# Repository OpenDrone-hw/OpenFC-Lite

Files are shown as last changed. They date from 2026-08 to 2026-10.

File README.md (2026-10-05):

# OpenFC-Lite

Open source Betaflight flight controller built on the RP2354B, 30.5 x 30.5 mm
mounting pattern, part of the incutec OpenDrone line.

<p>
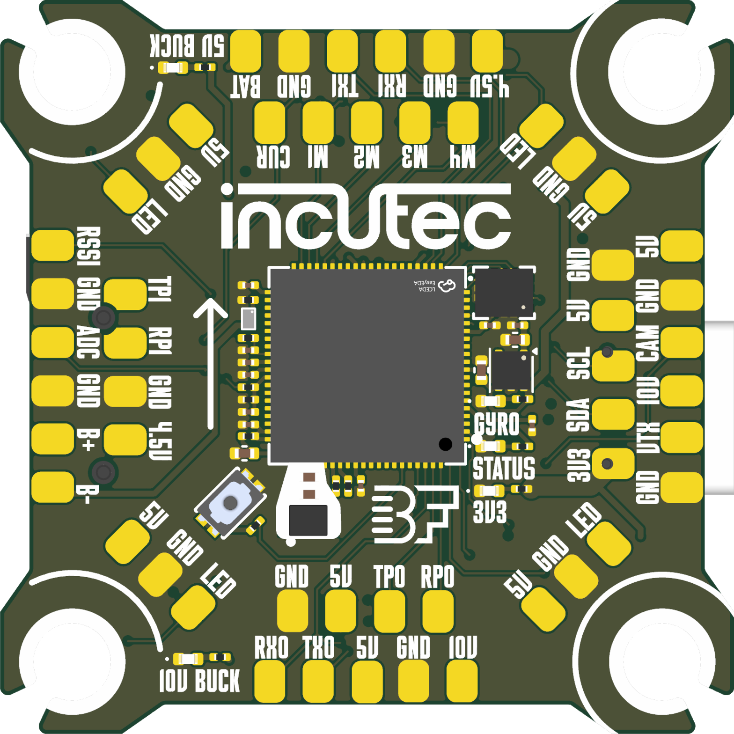
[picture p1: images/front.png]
OpenFC-Lite top

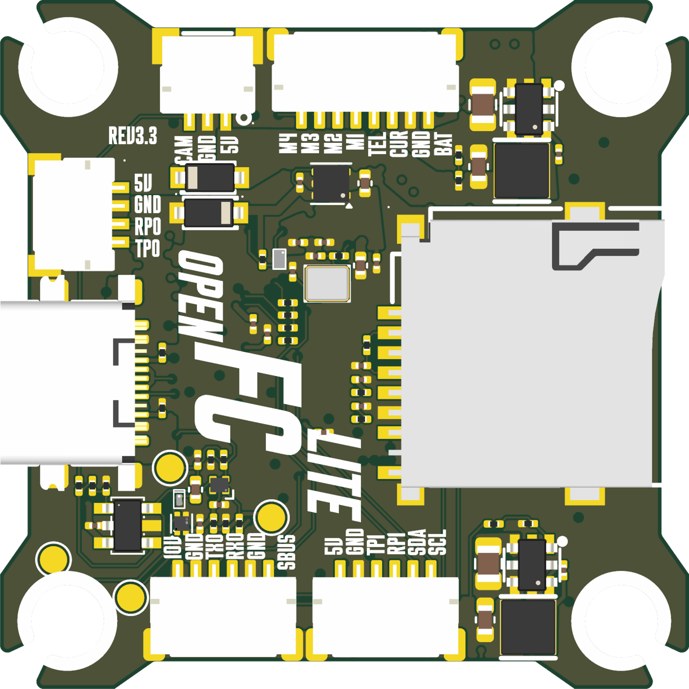
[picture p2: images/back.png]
OpenFC-Lite bottom

</p>







## Specifications

| | |
|---|---|
| Firmware | Betaflight |
| MCU | RP2354B |
| IMU | BMI270 |
| Barometer | None |
| Blackbox | microSD |
| OSD | Analog and digital |
| UARTs | 4 |
| Motor outputs | 4x DShot, bidirectional |
| RX | External, CRSF or SBUS |
| Input | 3-8S* LiPo (9.0-33.6 V) |
| BEC | 10 V switchable + 5 V always-on, 3.5 A |
| Current sense | Yes |
| USB | USB-C |
| Mounting | 30.5 x 30.5 mm, 4.0 mm holes |
| Dimensions | 37.9 x 37.9 mm |
| PCB | 6-layer, 1.6 mm |

* Also runs on 2S; the 10 V VTX output then follows the battery voltage instead of holding 10 V.

Technical write-up, part list and layout constraints: [AGENTS.md](AGENTS.md).

## In the line

What pairs with what, and what is available:
[opendrone.be](https://opendrone.be).

## Contributing

See [CONTRIBUTING.md](CONTRIBUTING.md).

## License

Hardware licensed under [CERN-OHL-S-2.0](https://ohwr.org/cern_ohl_s_v2.txt),
see [LICENSE](LICENSE).

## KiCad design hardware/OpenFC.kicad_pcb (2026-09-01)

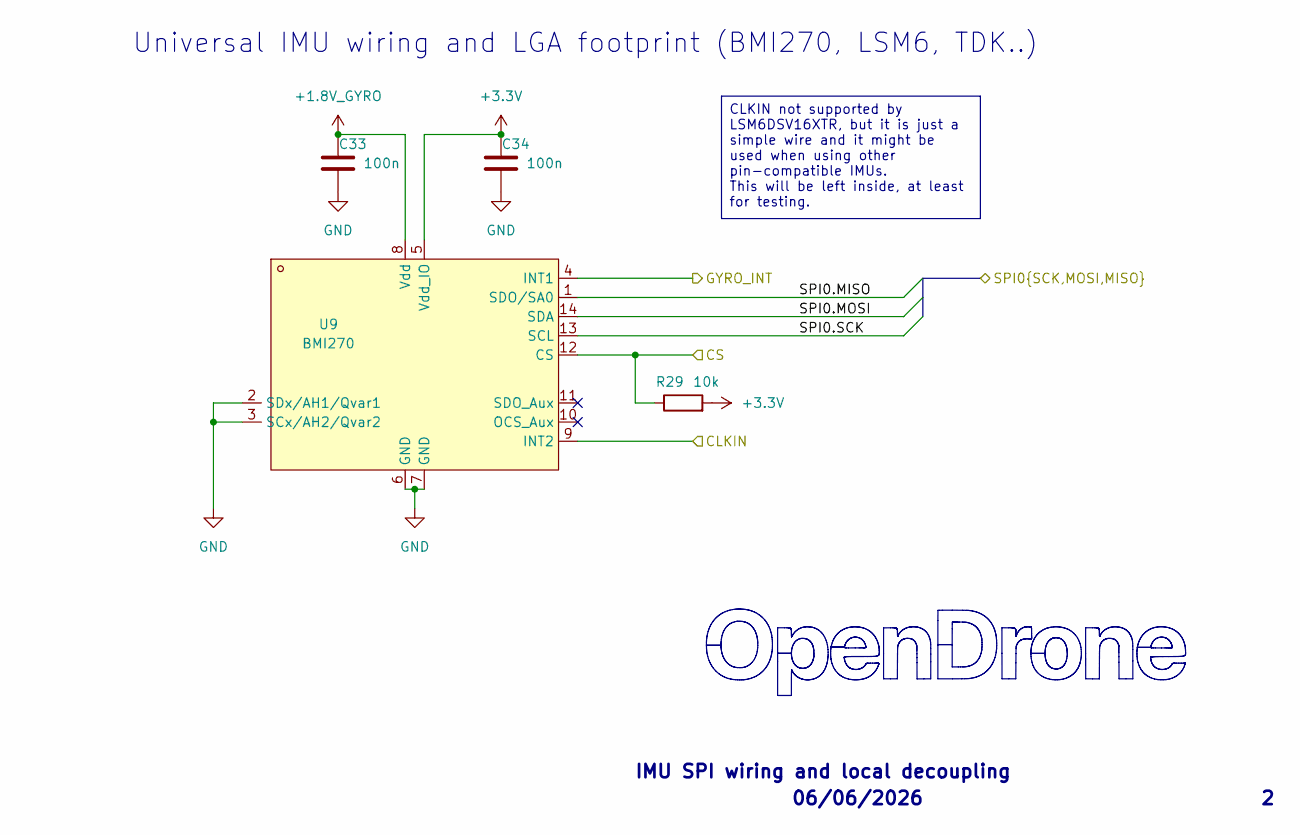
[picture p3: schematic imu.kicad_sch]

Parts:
C33, C34: 100n; C_0201_0603Metric; MPN GRM033R61E104KE14D; LCSC C76939
R29: 10k; R_0201_0603Metric; MPN RC0201FR-0710KL; LCSC C106225
U9: BMI270; LGA-14_L3.0-W2.5-P0.50-BR; MPN BMI270; LCSC C2836813

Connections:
+1.8V_GYRO: C33.1, U9.8 (Vdd); also elsewhere on the board
+3.3V: C34.1, R29.2, U9.5 (Vdd_IO); also elsewhere on the board
/IMU/CLKIN: U9.9 (INT2); also elsewhere on the board
/IMU/CS: R29.1, U9.12 (CS); also elsewhere on the board
/IMU/GYRO_INT: U9.4 (INT1); also elsewhere on the board
/IMU/SPI0.MISO: U9.1 (SDO/SA0); also elsewhere on the board
/IMU/SPI0.MOSI: U9.14 (SDA); also elsewhere on the board
/IMU/SPI0.SCK: U9.13 (SCL); also elsewhere on the board
GND: C33.2, C34.2, U9.2 (SDx/AH1/Qvar1), U9.3 (SCx/AH2/Qvar2), U9.6 (GND), U9.7 (GND); also elsewhere on the board

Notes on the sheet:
06/06/2026
IMU SPI wiring and local decoupling
Universal IMU wiring and LGA footprint (BMI270, LSM6, TDK..)
CLKIN not supported by LSM6DSV16XTR, but it is just a simple wire and it might be used when using other pin-compatible IMUs. This will be left inside, at least for testing.

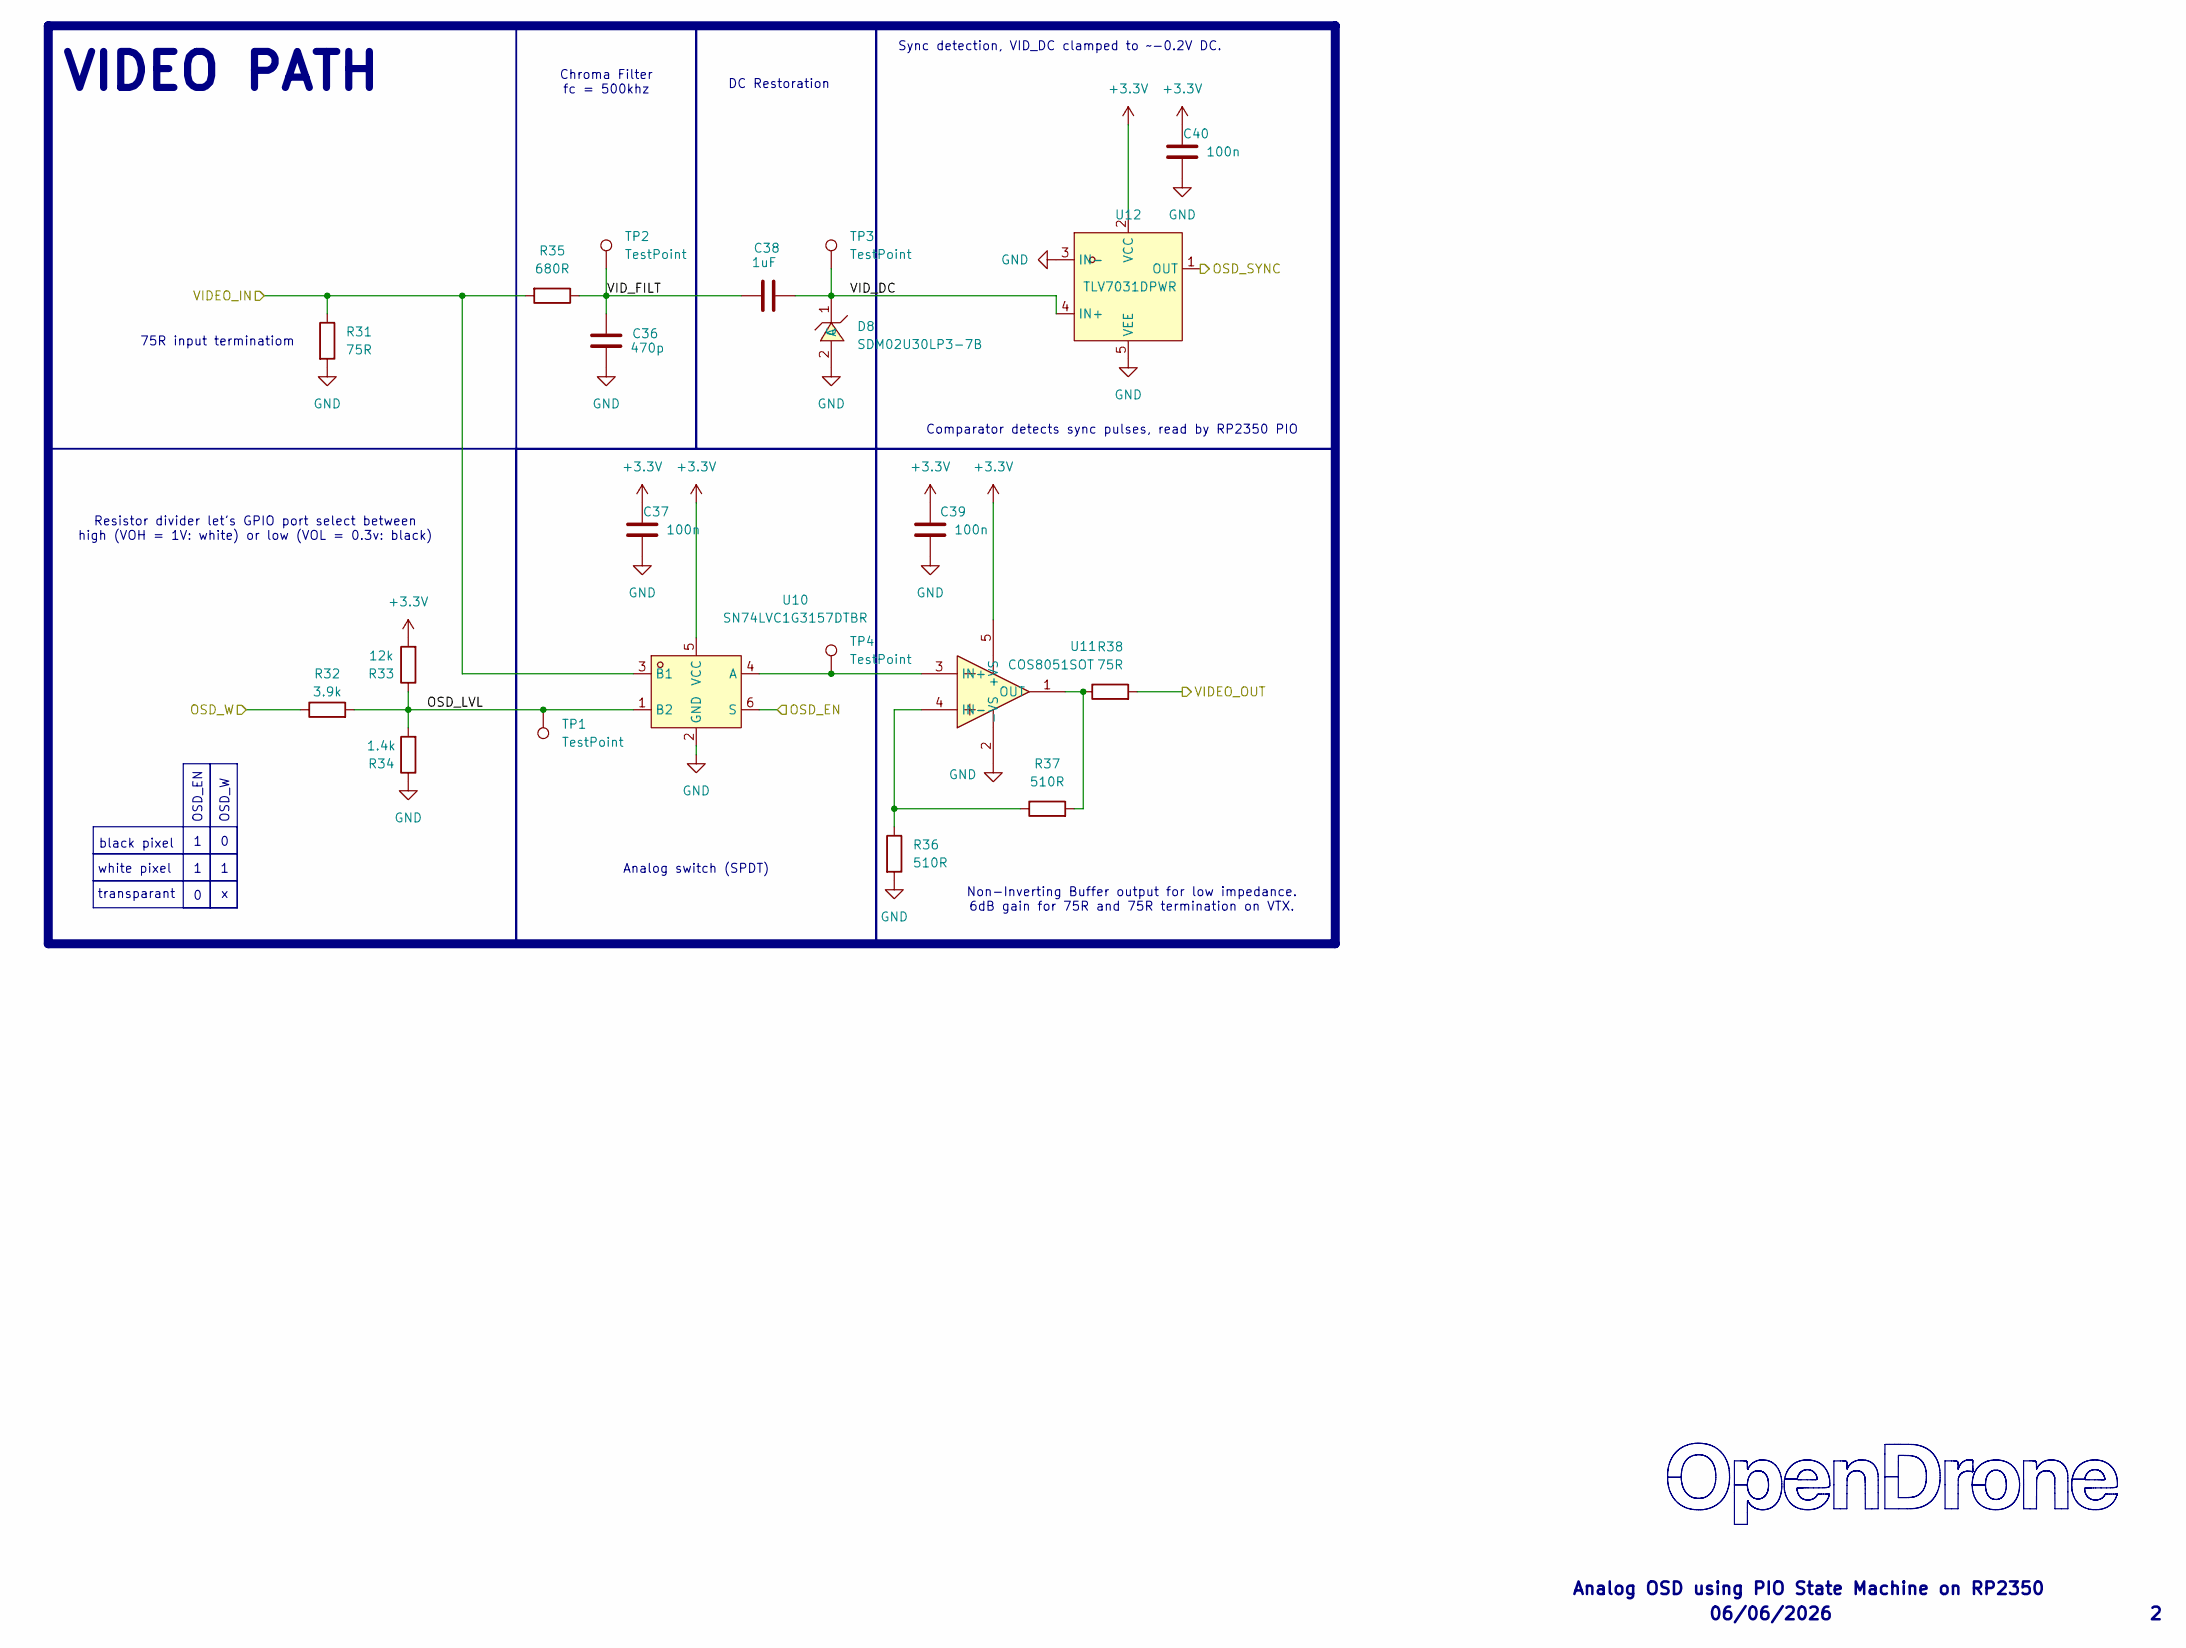
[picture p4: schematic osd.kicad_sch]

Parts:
C36: 470p; C_0201_0603Metric; MPN CC0201JRX7R9BB471; LCSC C526944
C37, C39, C40: 100n; C_0201_0603Metric; MPN GRM033R60J104KE19D; LCSC C76928
C38: 1uF; C_0402_1005Metric; MPN CL05A105KA5NQNC; LCSC C52923
D8: SDM02U30LP3-7B; X3-DFN0603-2_L0.6-W0.3-RD; MPN SDM02U30LP3-7B; LCSC C151629
R31, R38: 75R; R_0201_0603Metric; MPN RC0201FR-0775RL; LCSC C274878
R32: 3.9k; R_0201_0603Metric; MPN RC0201FR-073K9L; LCSC C273280
R33: 12k; R_0201_0603Metric; MPN 0201WMF1202TEE; LCSC C270363
R34: 1.4k; R_0201_0603Metric; MPN 0201WMF1401TEE; LCSC C423739
R35: 680R; R_0201_0603Metric; MPN 0201WMF6800TEE; LCSC C473509
R36, R37: 510R; R_0201_0603Metric; MPN RC0201FR-07510RL; LCSC C57784
TP1, TP2, TP3, TP4: TestPoint; TestPoint_Pad_D1.5mm
U10: SN74LVC1G3157DTBR; X2SON-6_L1.0-W0.8-BL; MPN SN74LVC1G3157DTBR; LCSC C2673087
U11: COS8051SOT; SOT-23-5_L3.0-W1.7-P0.95-LS2.8-BR; MPN COS8051SOT; LCSC C7463385
U12: TLV7031DPWR; X2SON-4_L0.8-W0.8-P0.48-TL-A; MPN TLV7031DPWR; LCSC C2876045

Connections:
+3.3V: C37.1, C39.1, C40.1, R33.2, U10.5 (VCC), U11.5 (+VS), U12.2 (VCC); also elsewhere on the board
/OSD/OSD_EN: U10.6 (S); also elsewhere on the board
/OSD/OSD_LVL: R32.2, R33.1, R34.2, TP1.1 (1_1), U10.1 (B2)
/OSD/OSD_SYNC: U12.1 (OUT); also elsewhere on the board
/OSD/OSD_W: R32.1; also elsewhere on the board
/OSD/VIDEO_IN: R31.1, R35.2, U10.3 (B1); also elsewhere on the board
/OSD/VIDEO_OUT: R38.2; also elsewhere on the board
/OSD/VID_DC: C38.2, D8.1 (C), TP3.1 (1_1), U12.4 (IN+)
/OSD/VID_FILT: C36.1, C38.1, R35.1, TP2.1 (1_1)
GND: C36.2, C37.2, C39.2, C40.2, D8.2 (A), R31.2, R34.1, R36.2, U10.2 (GND), U11.2 (-VS), U12.3 (IN-), U12.5 (VEE); also elsewhere on the board
unnamed: TP4.1 (1_1), U10.4 (A), U11.3 (IN+)
unnamed: R36.1, R37.1, U11.4 (IN-)
unnamed: R37.2, R38.1, U11.1 (OUT)

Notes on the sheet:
black pixel
Comparator detects sync pulses, read by RP2350 PIO
06/06/2026
Analog OSD using PIO State Machine on RP2350
Sync detection, VID_DC clamped to ~-0.2V DC.
Non-Inverting Buffer output for low impedance. 6dB gain for 75R and 75R termination on VTX.
white pixel
75R input terminatiom
OSD_W
Chroma Filter fc = 500khz
VIDEO PATH
Analog switch (SPDT)
OSD_EN
transparant
DC Restoration
Resistor divider let's GPIO port select between high (VOH = 1V: white) or low (VOL = 0.3v: black)

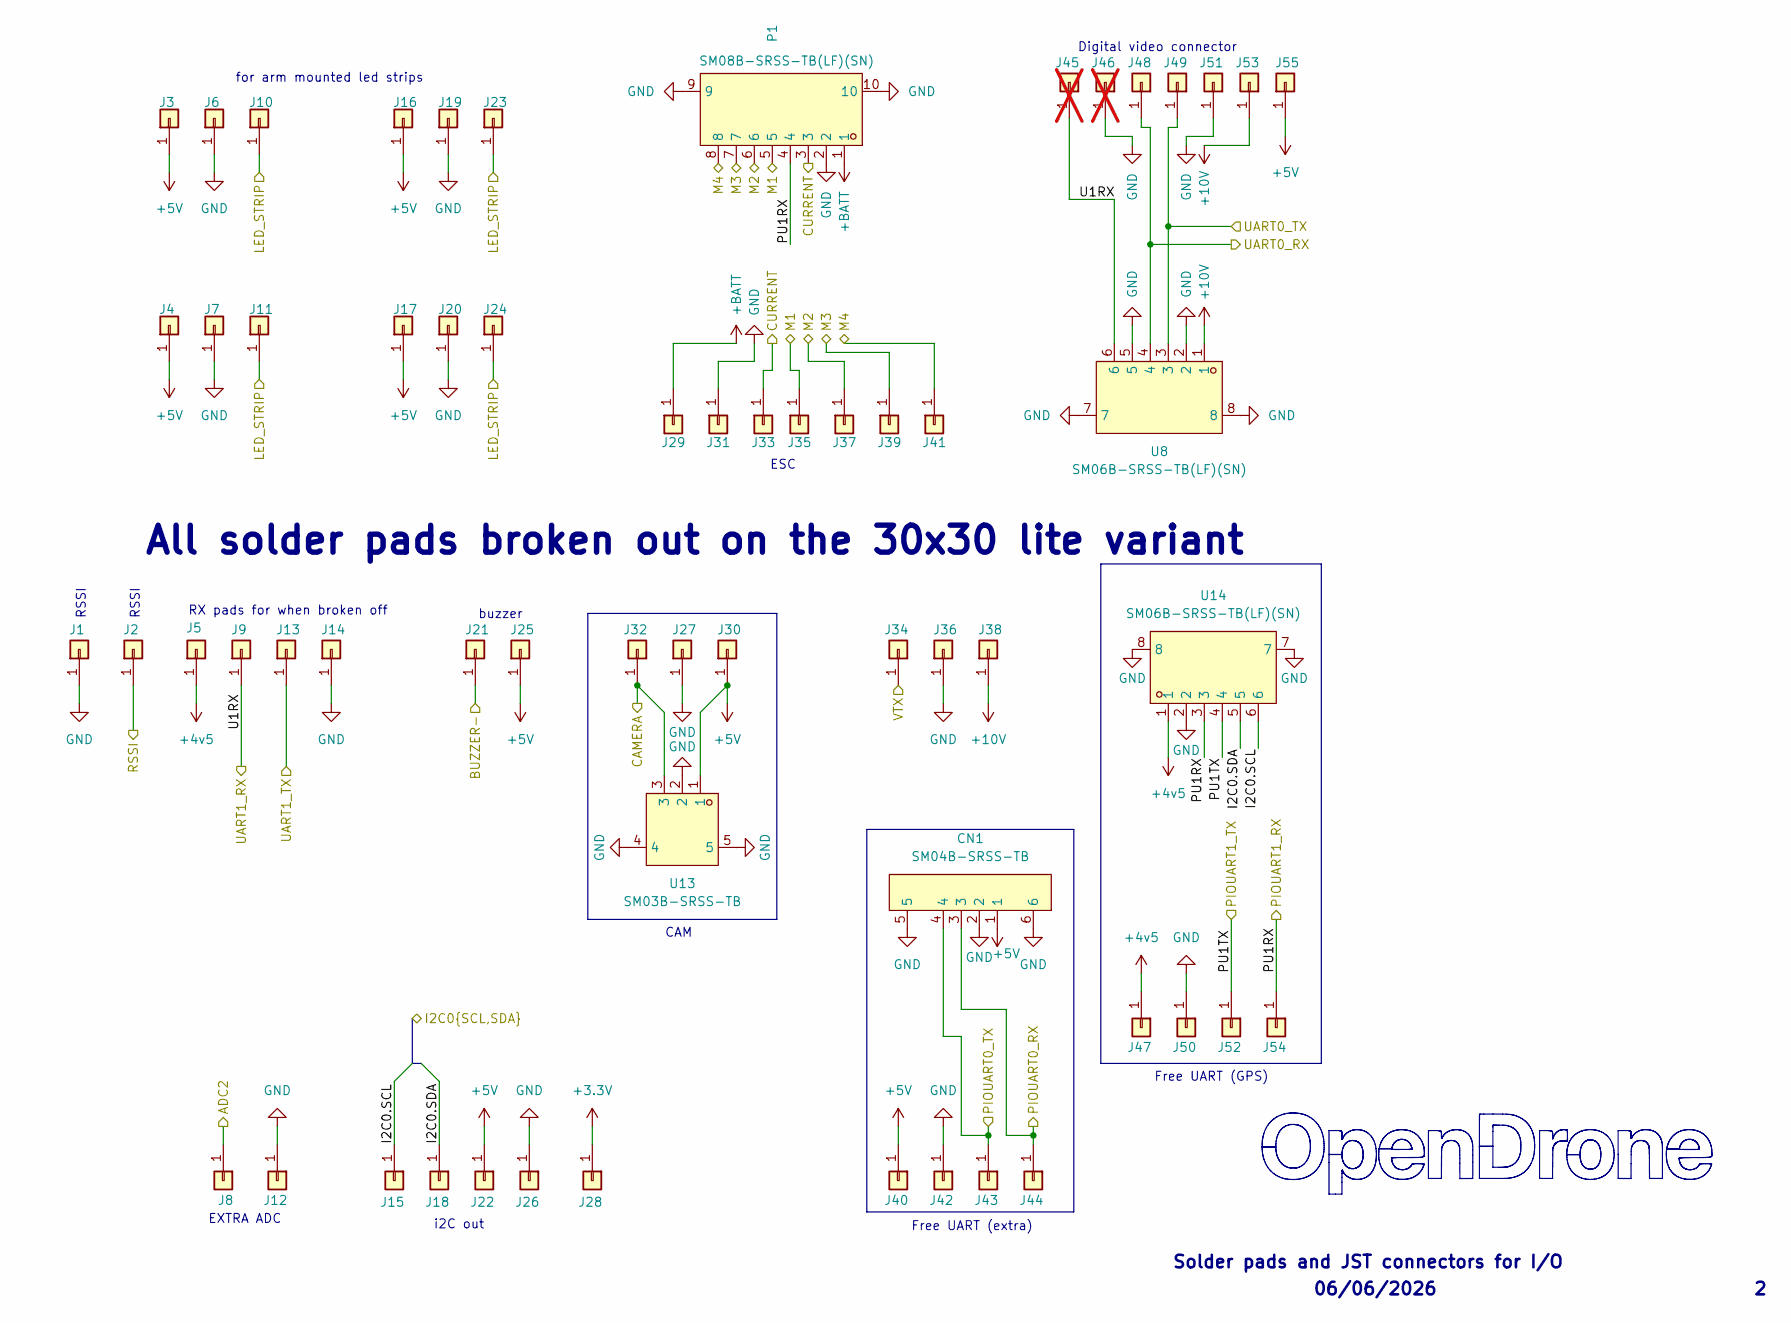
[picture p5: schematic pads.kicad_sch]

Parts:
CN1: SM04B-SRSS-TB; CONN-SMD_4P-P1.00_SM04B-SRSS-TB-LF-SN; MPN SM04B-SRSS-TB(LF)(SN); LCSC C160404
J1, J2, J3, J4, J5, J6, J7, J8, J9, J10, J11, J12, J13, J14, J15, J16, J17, J18, J19, J20, J21, J22, J23, J24, J25, J26, J27, J28, J29, J30, J31, J32, J33, J34, J35, J36, J37, J38, J39, J40, J41, J42, J43, J44, J47, J48, J49, J50, J51, J52, J53, J54, J55: 5V; small_pad
J45, J46: 5V; small_pad; not fitted
P1: SM08B-SRSS-TB(LF)(SN); CONN-TH_SM08B-SRSS-TB-LF-SN; MPN SM08B-SRSS-TB(LF)(SN); LCSC C160407
U8, U14: SM06B-SRSS-TB(LF)(SN); CONN-SMD_SM06B-SRSS-TB-LF-SN; MPN SM06B-SRSS-TB(LF)(SN); LCSC C160405
U13: SM03B-SRSS-TB; CONN-SMD_SM03B-SRSS-TB-LF-SN-P; MPN SM03B-SRSS-TB(LF)(SN); LCSC C160403

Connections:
+3.3V: J28.1 (Pin_1_1); also elsewhere on the board
+4v5: J5.1 (Pin_1_1), J47.1 (Pin_1_1), U14.1; also elsewhere on the board
+5V: CN1.1, J3.1 (Pin_1_1), J4.1 (Pin_1_1), J16.1 (Pin_1_1), J17.1 (Pin_1_1), J22.1 (Pin_1_1), J25.1 (Pin_1_1), J30.1 (Pin_1_1), J40.1 (Pin_1_1), J55.1 (Pin_1_1), U13.1; also elsewhere on the board
+10V: J38.1 (Pin_1_1), J53.1 (Pin_1_1), U8.1; also elsewhere on the board
+BATT: J29.1 (Pin_1_1), P1.1; also elsewhere on the board
/OSD/VIDEO_IN: J32.1 (Pin_1_1), U13.3; also elsewhere on the board
/OSD/VIDEO_OUT: J34.1 (Pin_1_1); also elsewhere on the board
/PADS/ADC2: J8.1 (Pin_1_1); also elsewhere on the board
/PADS/BUZZER-: J21.1 (Pin_1_1); also elsewhere on the board
/PADS/CURRENT: J33.1 (Pin_1_1), P1.3; also elsewhere on the board
/PADS/I2C0.SCL: J15.1 (Pin_1_1), U14.6; also elsewhere on the board
/PADS/I2C0.SDA: J18.1 (Pin_1_1), U14.5; also elsewhere on the board
/PADS/LED_STRIP: J10.1 (Pin_1_1), J11.1 (Pin_1_1), J23.1 (Pin_1_1), J24.1 (Pin_1_1); also elsewhere on the board
/PADS/M1: J35.1 (Pin_1_1), P1.5; also elsewhere on the board
/PADS/M2: J37.1 (Pin_1_1), P1.6; also elsewhere on the board
/PADS/M3: J39.1 (Pin_1_1), P1.7; also elsewhere on the board
/PADS/M4: J41.1 (Pin_1_1), P1.8; also elsewhere on the board
/PADS/PIOUART0_RX: CN1.3, J44.1 (Pin_1_1); also elsewhere on the board
/PADS/PIOUART0_TX: CN1.4, J43.1 (Pin_1_1); also elsewhere on the board
/PADS/PU1RX: J54.1 (Pin_1_1), P1.4, U14.3; also elsewhere on the board
/PADS/PU1TX: J52.1 (Pin_1_1), U14.4; also elsewhere on the board
/PADS/RSSI: J2.1 (Pin_1_1); also elsewhere on the board
/PADS/U1RX: J9.1 (Pin_1_1), J45.1, U8.6; also elsewhere on the board
/PADS/UART0_RX: J48.1 (Pin_1_1), U8.4; also elsewhere on the board
/PADS/UART0_TX: J49.1 (Pin_1_1), U8.3; also elsewhere on the board
/PADS/UART1_TX: J13.1 (Pin_1_1); also elsewhere on the board
GND: CN1.2, CN1.5, CN1.6, J1.1 (Pin_1_1), J6.1 (Pin_1_1), J7.1 (Pin_1_1), J12.1 (Pin_1_1), J14.1 (Pin_1_1), J19.1 (Pin_1_1), J20.1 (Pin_1_1), J26.1 (Pin_1_1), J27.1 (Pin_1_1), J31.1 (Pin_1_1), J36.1 (Pin_1_1), J42.1 (Pin_1_1), J46.1, J50.1 (Pin_1_1), J51.1 (Pin_1_1), P1.2, P1.9, P1.10, U8.2, U8.5, U8.7, U8.8, U13.2, U13.4, U13.5, U14.2, U14.7, U14.8; also elsewhere on the board

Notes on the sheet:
06/06/2026
RSSI
Free UART (extra)
Solder pads and JST connectors for I/O
i2C out
CAM
All solder pads broken out on the 30x30 lite variant
Free UART (GPS)
buzzer
RX pads for when broken off
ESC
Digital video connector
EXTRA ADC
for arm mounted led strips

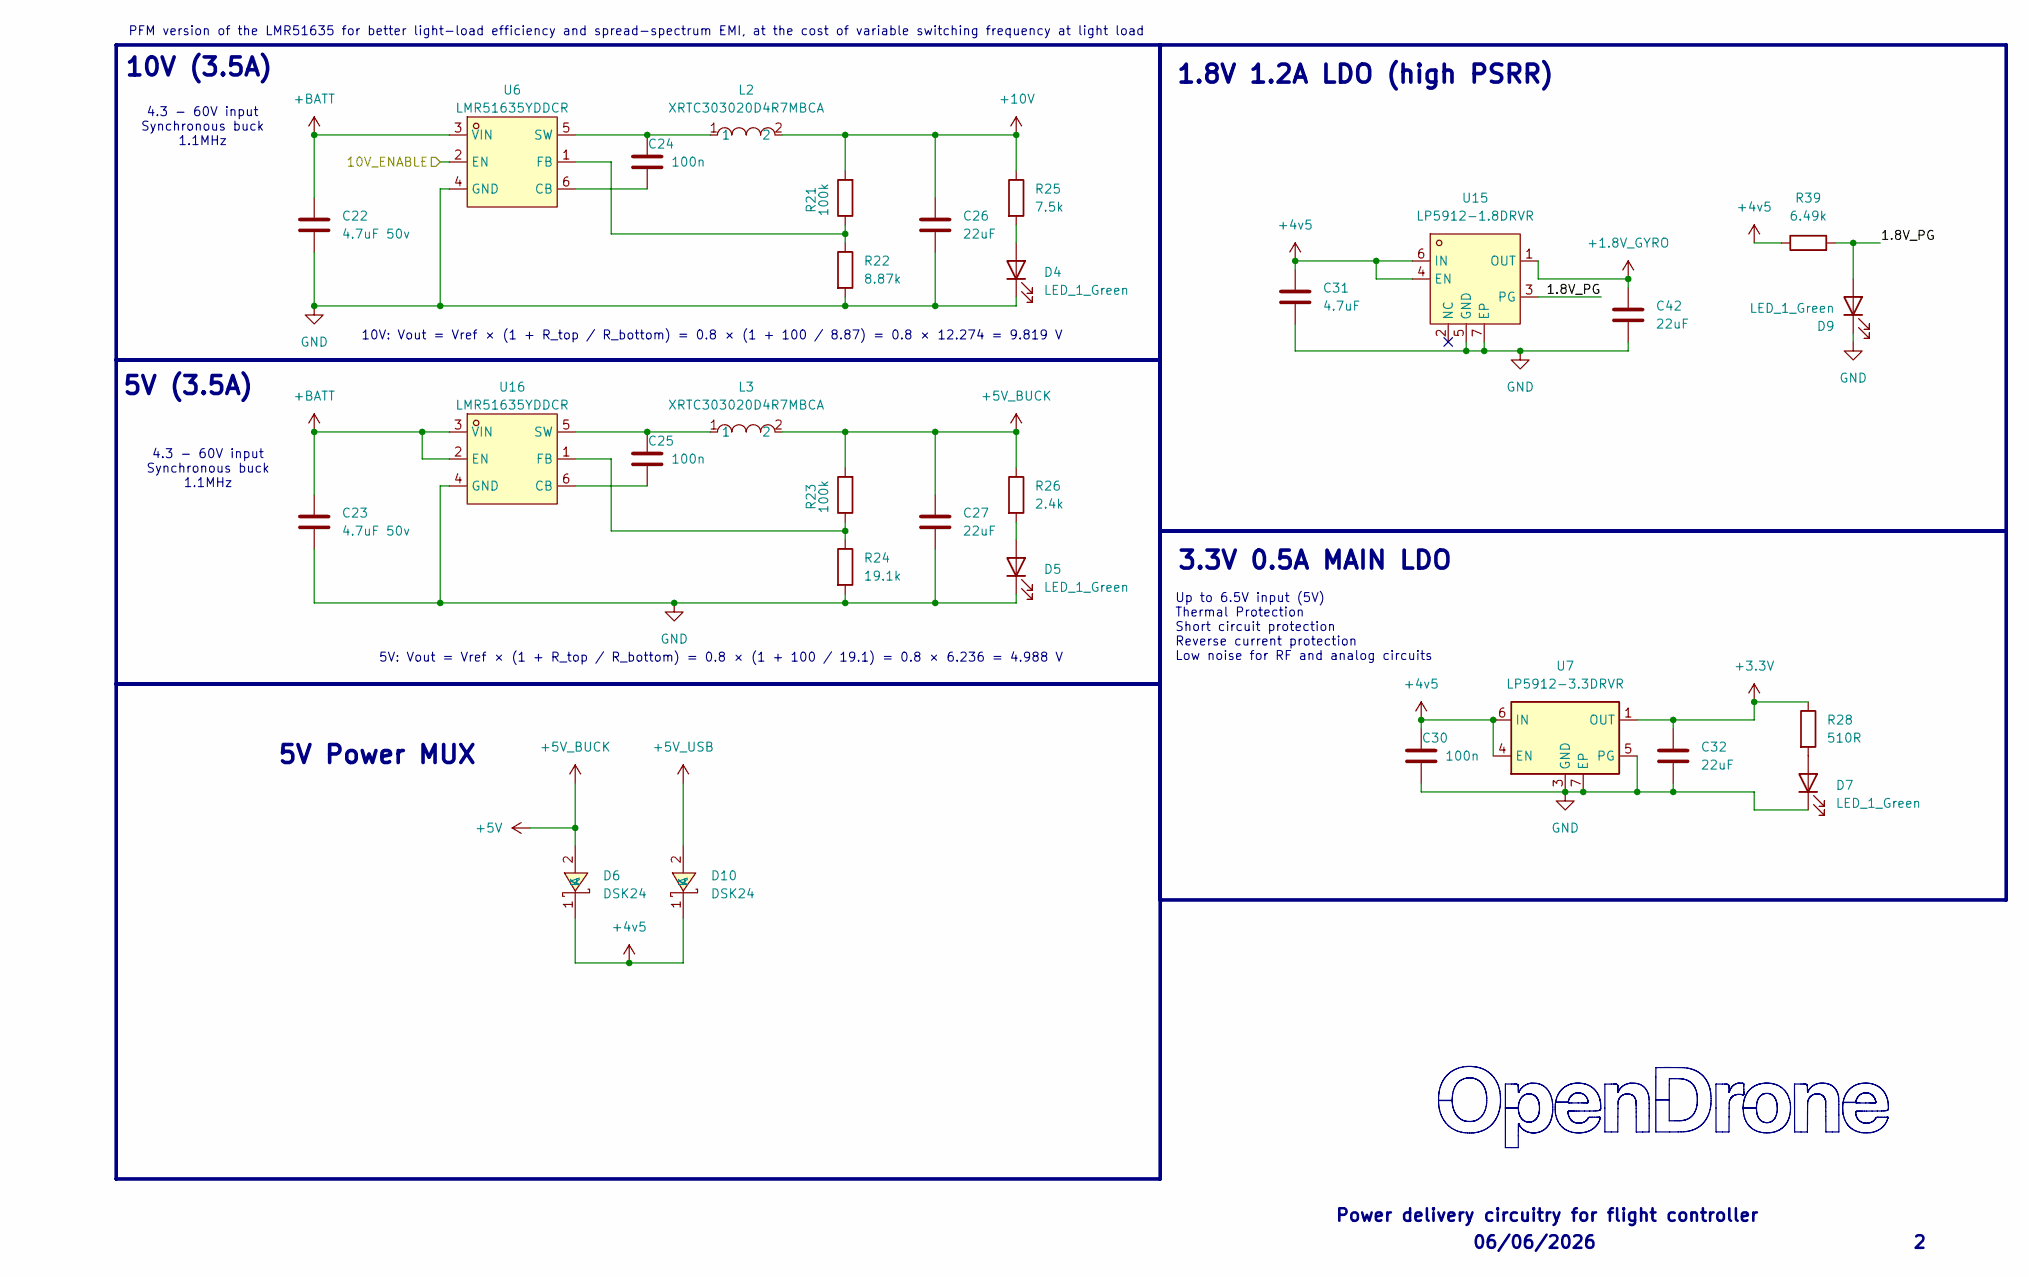
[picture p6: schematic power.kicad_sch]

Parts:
C22, C23: 4.7uF 50v; C_0805_2012Metric; MPN CL21A475KBQNNNE; LCSC C98192
C24, C25, C30: 100n; C_0201_0603Metric; MPN GRM033R61E104KE14D; LCSC C76939
C26, C27: 22uF; C_0603_1608Metric; MPN CL10A226MO7JZNC; LCSC C2762594
C31: 4.7uF; C_0402_1005Metric; MPN CL05A475MP5NRNC; LCSC C23733
C32: 22uF; C_0402_1005Metric; MPN CL05A226MQ5QUNC; LCSC C105226
C42: 22uF; C_0402_1005Metric; MPN GRM155R60J226ME11D; LCSC C415703
D4, D5, D7, D9: LED_1_Green; LED_0402_1005Metric; MPN XL-1005UGC; LCSC C965793
D6, D10: DSK24; SOD-123_L2.8-W1.8-LS3.7-RD; MPN DSK24; LCSC C64890
L2, L3: XRTC303020D4R7MBCA; IND-SMD_L3.0-W3.0_AFE303020S; MPN XRTC303020D4R7MBCA; LCSC C39846837
R21, R23: 100k; R_0201_0603Metric; MPN 0201WMF1003TEE; LCSC C270364
R22: 8.87k; R_0201_0603Metric; MPN RTT018871FTH; LCSC C332577
R24: 19.1k; R_0201_0603Metric; MPN RC-01W1912FT; LCSC C320741
R25: 7.5k; R_0201_0603Metric; MPN RC0201FR-077K5L; LCSC C474437
R26: 2.4k; R_0201_0603Metric; MPN RTT012401FTH; LCSC C166281
R28: 510R; R_0201_0603Metric; MPN RC0201FR-07510RL; LCSC C57784
R39: 6.49k; R_0201_0603Metric; MPN AF0201FR-076K49L; LCSC C2107920
U6, U16: LMR51635YDDCR; SOT-23-6_L2.9-W1.6-P0.95-LS2.8-BL; MPN LMR51635YDDCR; LCSC C45262770
U7: LP5912-3.3DRVR; WSON-6-1EP_2x2mm_P0.65mm_EP1x1.6mm; MPN LP5912-3.3DRVR; LCSC C524780
U15: LP5912-1.8DRVR; WSON-6-1EP_2x2mm_P0.65mm_EP1x1.6mm_ThermalVias; MPN LP5912-1.8DRVR; LCSC C2876234

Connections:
+1.8V_GYRO: C42.1, U15.1 (OUT); also elsewhere on the board
+3.3V: C32.1, R28.1, U7.1 (OUT); also elsewhere on the board
+4v5: C30.1, C31.1, D6.1 (K), D10.1 (K), R39.1, U7.4 (EN), U7.6 (IN), U15.4 (EN), U15.6 (IN); also elsewhere on the board
+5V: C27.1, D6.2 (A), L3.2, R23.2, R26.1; also elsewhere on the board
+5V_USB: D10.2 (A); also elsewhere on the board
+10V: C26.1, L2.2, R21.2, R25.1; also elsewhere on the board
+BATT: C22.1, C23.1, U6.3 (VIN), U16.2 (EN), U16.3 (VIN); also elsewhere on the board
/POWER/1.8V_PG: D9.2 (A), R39.2, U15.3 (PG)
/POWER/10V_ENABLE: U6.2 (EN); also elsewhere on the board
GND: C22.2, C23.2, C26.2, C27.2, C30.2, C31.2, C32.2, C42.2, D4.1 (K), D5.1 (K), D7.1 (K), D9.1 (K), R22.2, R24.2, U6.4 (GND), U7.3 (GND), U7.5 (PG), U7.7 (EP), U15.5 (GND), U15.7 (EP), U16.4 (GND); also elsewhere on the board
unnamed: D4.2 (A), R25.2
unnamed: D5.2 (A), R26.2
unnamed: D7.2 (A), R28.2
unnamed: C24.2, U6.6 (CB)
unnamed: R21.1, R22.1, U6.1 (FB)
unnamed: C24.1, L2.1, U6.5 (SW)
unnamed: C25.2, U16.6 (CB)
unnamed: R23.1, R24.1, U16.1 (FB)
unnamed: C25.1, L3.1, U16.5 (SW)

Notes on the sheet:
5V Power MUX
4.3 - 60V input Synchronous buck 1.1MHz
Power delivery circuitry for flight controller
06/06/2026
10V: Vout = Vref × (1 + R_top / R_bottom) = 0.8 × (1 + 100 / 8.87) = 0.8 × 12.274 = 9.819 V
5V: Vout = Vref × (1 + R_top / R_bottom) = 0.8 × (1 + 100 / 19.1) = 0.8 × 6.236 = 4.988 V
Up to 6.5V input (5V) Thermal Protection Short circuit protection Reverse current protection Low noise for RF and analog circuits
5V (3.5A)
1.8V 1.2A LDO (high PSRR)
PFM version of the LMR51635 for better light-load efficiency and spread-spectrum EMI, at the cost of variable switching frequency at light load
10V (3.5A)
3.3V 0.5A MAIN LDO

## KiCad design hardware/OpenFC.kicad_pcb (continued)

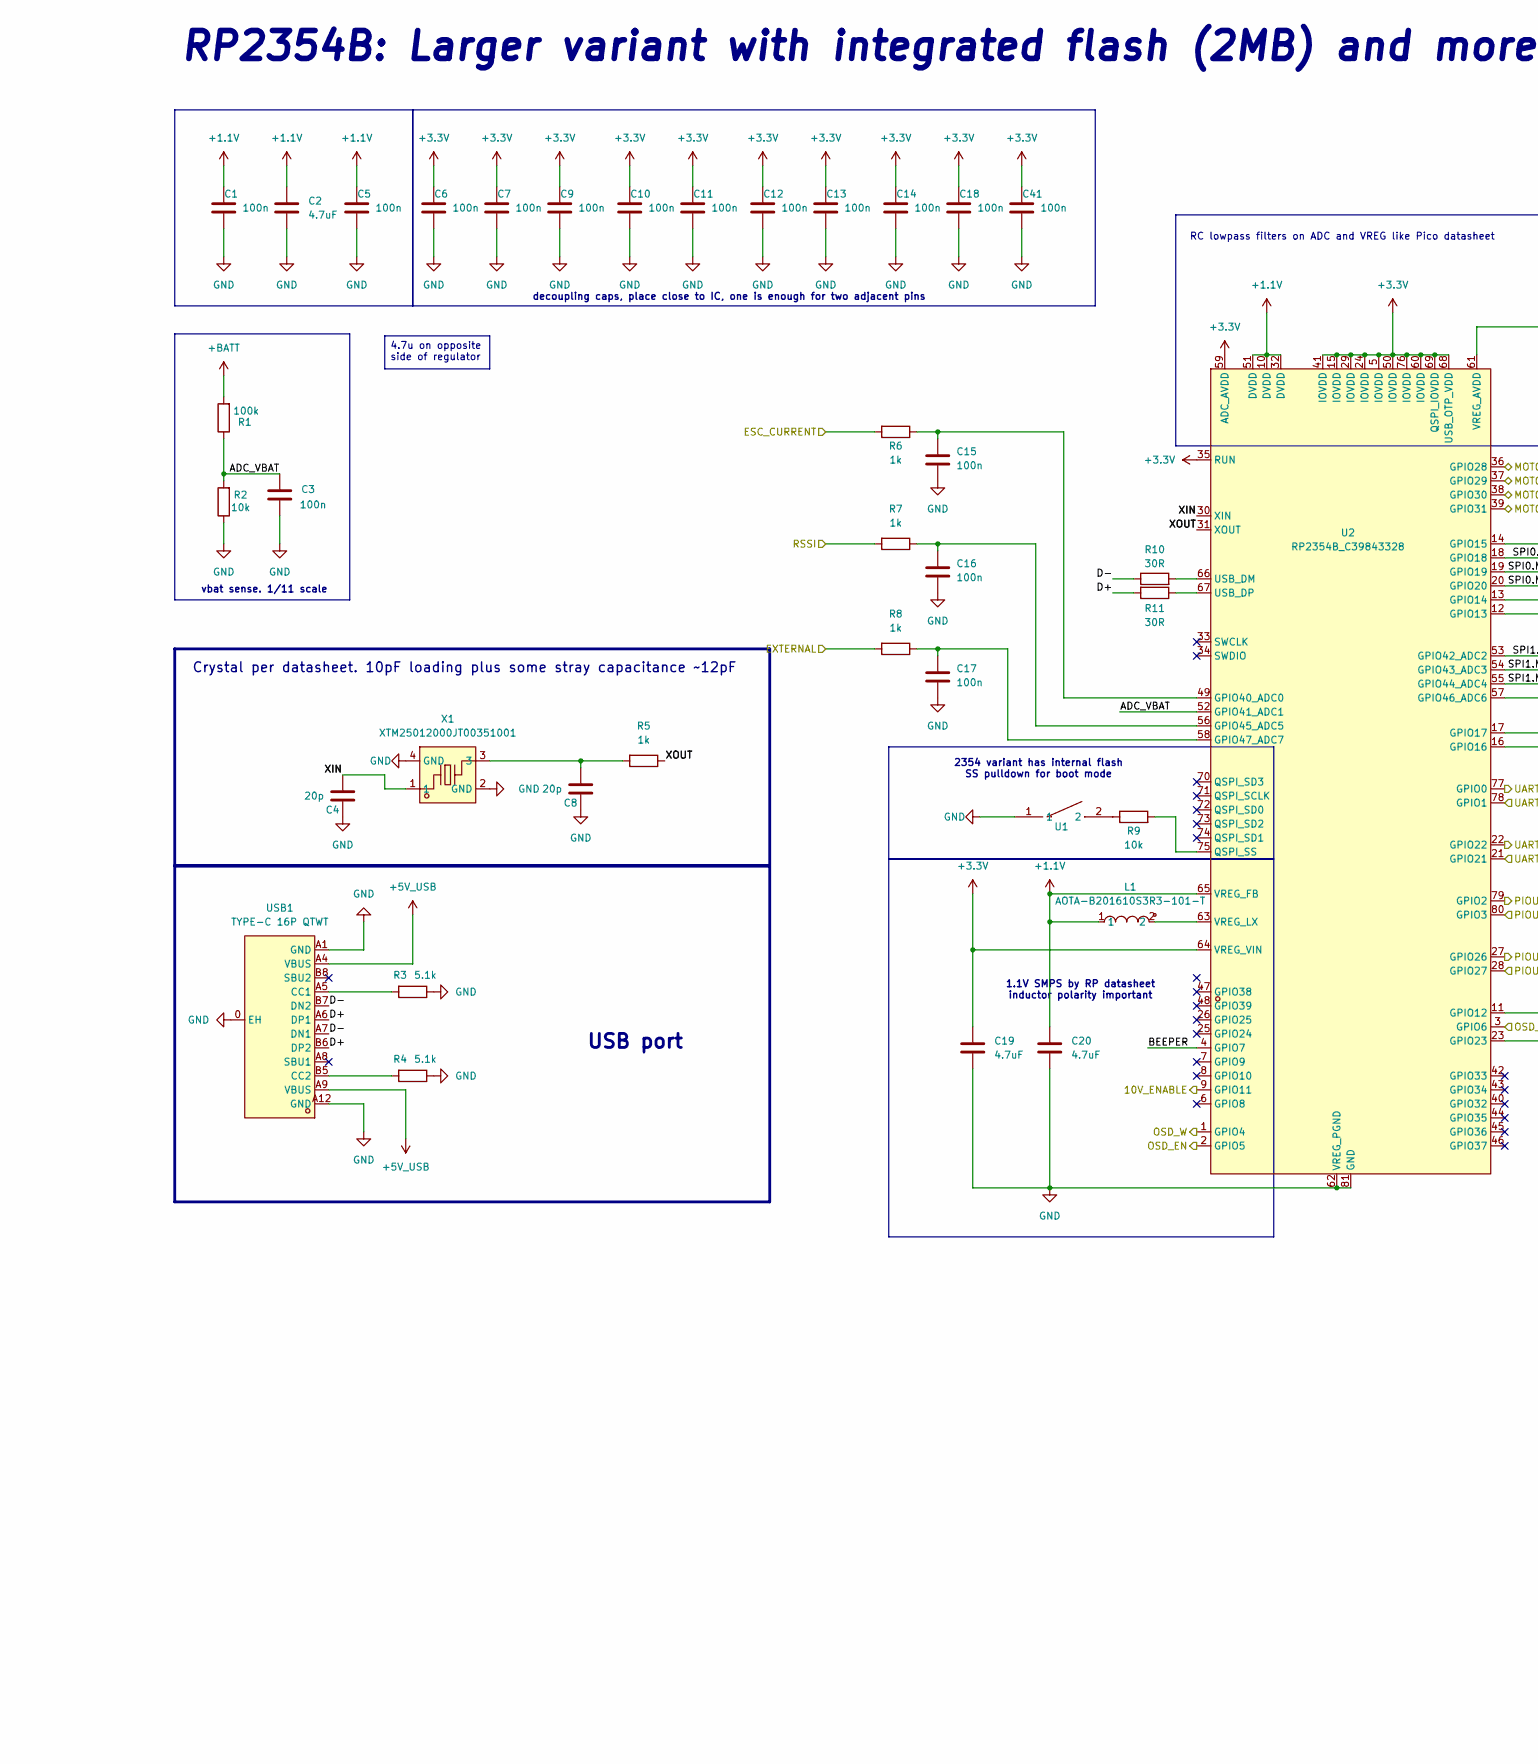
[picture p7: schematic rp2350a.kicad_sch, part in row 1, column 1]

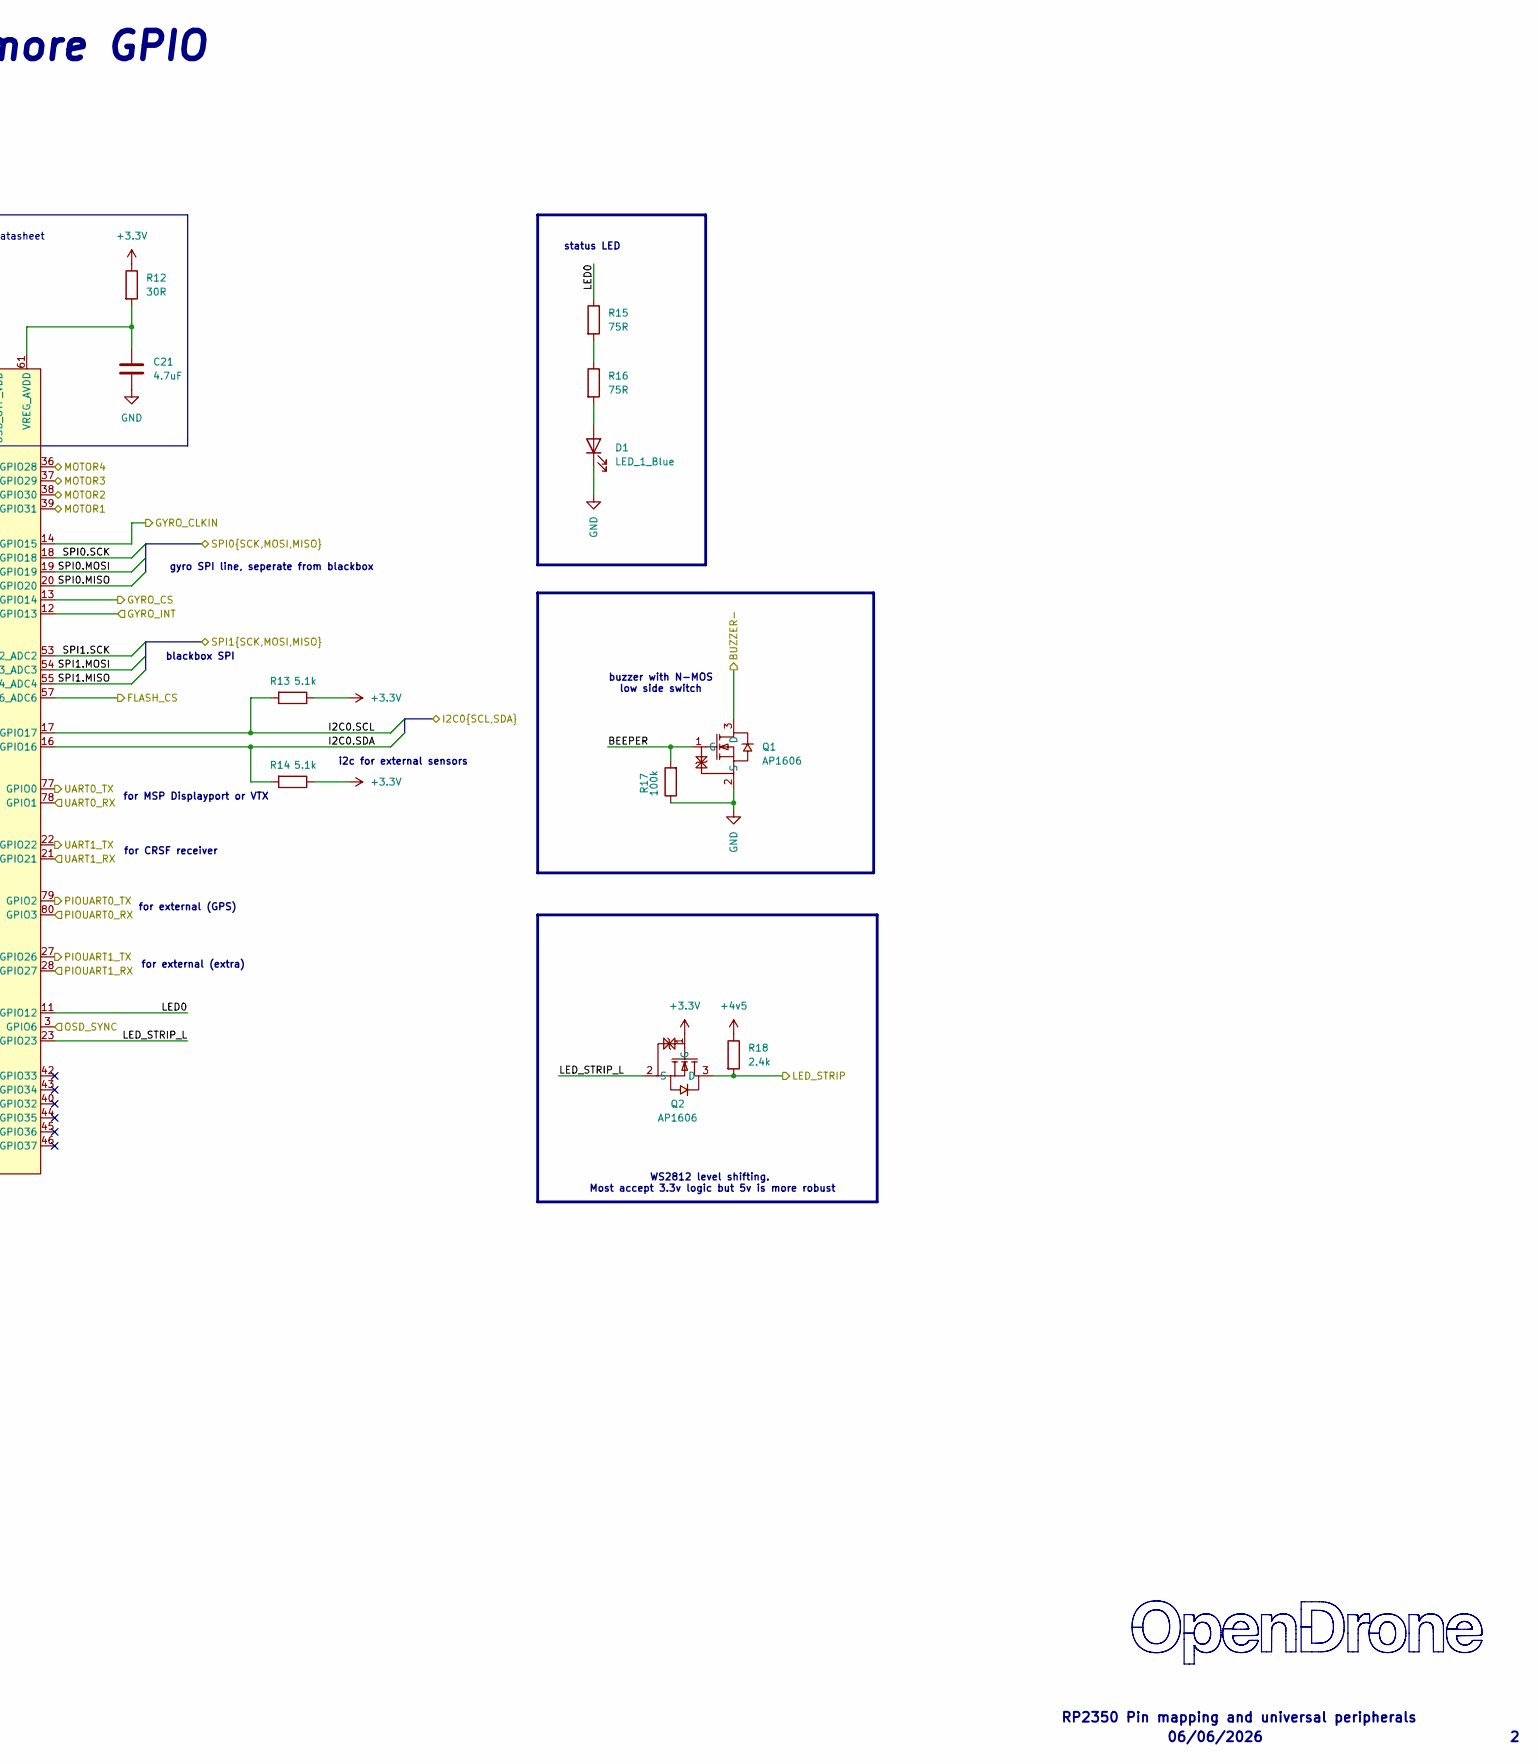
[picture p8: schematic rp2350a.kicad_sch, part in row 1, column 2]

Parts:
C1, C3, C5, C6, C7, C9, C10, C11, C12, C13, C14, C15, C16, C17, C18, C41: 100n; C_0201_0603Metric; MPN GRM033R61E104KE14D; LCSC C76939
C2, C19, C20, C21: 4.7uF; C_0402_1005Metric; MPN CL05A475MP5NRNC; LCSC C23733
C4, C8: 20p; C_0201_0603Metric; MPN GRM0335C1H200JA01D; LCSC C76923
D1: LED_1_Blue; LED_0402_1005Metric; MPN XL-1005UBC; LCSC C22355736
L1: AOTA-B201610S3R3-101-T; IND-SMD_L2.0-W1.6_AOTA-B201610S3R3-101-T; MPN AOTA-B201610S3R3-101-T; LCSC C42411119
Q1, Q2: AP1606; DFN-3L_L1.0-W0.6-P0.65-BR; MPN AP1606; LCSC C2849580
R1, R17: 100k; R_0201_0603Metric; MPN 0201WMF1003TEE; LCSC C270364
R2, R9: 10k; R_0201_0603Metric; MPN RC0201FR-0710KL; LCSC C106225
R3, R4, R13, R14: 5.1k; R_0201_0603Metric; MPN 0201WMF5101TEE; LCSC C270344
R5, R6, R7, R8: 1k; R_0201_0603Metric; MPN 0201WMF1001TEE; LCSC C270365
R10, R11, R12: 30R; R_0201_0603Metric; MPN NQ01WMJ0300TEE; LCSC C778391
R15, R16: 75R; R_0201_0603Metric; MPN RC0201FR-0775RL; LCSC C274878
R18: 2.4k; R_0201_0603Metric; MPN RTT012401FTH; LCSC C166281
U1: TS2306A 240GF MSM 9_C2976675; SW-SMD_4P-L3.0-W2.0-P0.85-LS3.5; MPN TS2306A 240gf MSM 9; LCSC C2976675
U2: RP2354B_C39843328; QFN-80_L10.0-W10.0-P0.40-TL-EP3.4; MPN RP2354B; LCSC C39843328
USB1: TYPE-C 16P QTWT; USB-TYPE-C-SMD_TYPE-C-16P-QTWT; MPN TYPE-C 16P QTWT; LCSC C5187472
X1: XTM25012000JT00351001; CRYSTAL-SMD_4P-L2.5-W2.0-BL-A; MPN XTM25012000JT00351001; LCSC C37635340

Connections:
+1.1V: C1.1, C2.1, C5.1, C20.1, L1.1, U2.10 (DVDD), U2.32 (DVDD), U2.51 (DVDD), U2.65 (VREG_FB)
+3.3V: C6.1, C7.1, C9.1, C10.1, C11.1, C12.1, C13.1, C14.1, C18.1, C19.1, C41.1, Q2.1 (G), R12.1, R13.1, R14.1, U2.5 (IOVDD), U2.15 (IOVDD), U2.24 (IOVDD), U2.29 (IOVDD), U2.35 (RUN), U2.41 (IOVDD), U2.50 (IOVDD), U2.59 (ADC_AVDD), U2.60 (IOVDD), U2.64 (VREG_VIN), U2.68 (USB_OTP_VDD), U2.69 (QSPI_IOVDD), U2.76 (IOVDD); also elsewhere on the board
+4v5: R18.1; also elsewhere on the board
+5V_USB: USB1.A4 (VBUS), USB1.A9 (VBUS); also elsewhere on the board
+BATT: R1.2; also elsewhere on the board
/BLACKBOX/FLASH_CS: U2.57 (GPIO46_ADC6); also elsewhere on the board
/BLACKBOX/SPI1.MISO: U2.55 (GPIO44_ADC4); also elsewhere on the board
/BLACKBOX/SPI1.MOSI: U2.54 (GPIO43_ADC3); also elsewhere on the board
/BLACKBOX/SPI1.SCK: U2.53 (GPIO42_ADC2); also elsewhere on the board
/IMU/CLKIN: U2.14 (GPIO15); also elsewhere on the board
/IMU/CS: U2.13 (GPIO14); also elsewhere on the board
/IMU/GYRO_INT: U2.12 (GPIO13); also elsewhere on the board
/IMU/SPI0.MISO: U2.20 (GPIO20); also elsewhere on the board
/IMU/SPI0.MOSI: U2.19 (GPIO19); also elsewhere on the board
/IMU/SPI0.SCK: U2.18 (GPIO18); also elsewhere on the board
/OSD/OSD_EN: U2.2 (GPIO5); also elsewhere on the board
/OSD/OSD_SYNC: U2.3 (GPIO6); also elsewhere on the board
/OSD/OSD_W: U2.1 (GPIO4); also elsewhere on the board
/PADS/ADC2: R8.2; also elsewhere on the board
/PADS/BUZZER-: Q1.3 (D); also elsewhere on the board
/PADS/CURRENT: R6.2; also elsewhere on the board
/PADS/I2C0.SCL: R13.2, U2.17 (GPIO17); also elsewhere on the board
/PADS/I2C0.SDA: R14.2, U2.16 (GPIO16); also elsewhere on the board
/PADS/LED_STRIP: Q2.3 (D), R18.2; also elsewhere on the board
/PADS/M1: U2.39 (GPIO31); also elsewhere on the board
/PADS/M2: U2.38 (GPIO30); also elsewhere on the board
/PADS/M3: U2.37 (GPIO29); also elsewhere on the board
/PADS/M4: U2.36 (GPIO28); also elsewhere on the board
/PADS/PIOUART0_RX: U2.80 (GPIO3); also elsewhere on the board
/PADS/PIOUART0_TX: U2.79 (GPIO2); also elsewhere on the board
/PADS/PU1RX: U2.28 (GPIO27); also elsewhere on the board
/PADS/PU1TX: U2.27 (GPIO26); also elsewhere on the board
/PADS/RSSI: R7.2; also elsewhere on the board
/PADS/U1RX: U2.21 (GPIO21); also elsewhere on the board
/PADS/UART0_RX: U2.78 (GPIO1); also elsewhere on the board
/PADS/UART0_TX: U2.77 (GPIO0); also elsewhere on the board
/PADS/UART1_TX: U2.22 (GPIO22); also elsewhere on the board
/POWER/10V_ENABLE: U2.9 (GPIO11); also elsewhere on the board
/RP2350A/ADC_VBAT: C3.2, R1.1, R2.2, U2.52 (GPIO41_ADC1)
/RP2350A/BEEPER: Q1.1 (G), R17.2, U2.4 (GPIO7)
/RP2350A/D+: R11.2, USB1.A6 (DP1), USB1.B6 (DP2)
/RP2350A/D-: R10.1, USB1.A7 (DN1), USB1.B7 (DN2)
/RP2350A/LED0: R15.1, U2.11 (GPIO12)
/RP2350A/LED_STRIP_L: Q2.2 (S), U2.23 (GPIO23)
/RP2350A/XIN: C4.2, U2.30 (XIN), X1.1
/RP2350A/XOUT: R5.1, U2.31 (XOUT)
GND: C1.2, C2.2, C3.1, C4.1, C5.2, C6.2, C7.2, C8.1, C9.2, C10.2, C11.2, C12.2, C13.2, C14.2, C15.2, C16.2, C17.2, C18.2, C19.2, C20.2, C21.2, C41.2, D1.1 (K), Q1.2 (S), R2.1, R3.1, R4.1, R17.1, U1.1, U2.62 (VREG_PGND), U2.81 (GND), USB1.0 (EH), USB1.A1 (GND), USB1.A12 (GND), X1.2 (GND), X1.4 (GND); also elsewhere on the board
unnamed: C8.2, R5.2, X1.3
unnamed: D1.2 (A), R16.2
unnamed: R9.1, U1.2
unnamed: R15.2, R16.1
unnamed: C15.1, R6.1, U2.49 (GPIO40_ADC0)
unnamed: C16.1, R7.1, U2.56 (GPIO45_ADC5)
unnamed: C17.1, R8.1, U2.58 (GPIO47_ADC7)
unnamed: R9.2, U2.75 (QSPI_SS)
unnamed: R10.2, U2.66 (USB_DM)
unnamed: R11.1, U2.67 (USB_DP)
unnamed: C21.1, R12.2, U2.61 (VREG_AVDD)
unnamed: L1.2, U2.63 (VREG_LX)
unnamed: R3.2, USB1.A5 (CC1)
unnamed: R4.2, USB1.B5 (CC2)

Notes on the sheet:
RP2350 Pin mapping and universal peripherals
vbat sense. 1/11 scale
RP2354B: Larger variant with integrated flash (2MB) and more GPIO
blackbox SPI
06/06/2026
for MSP Displayport or VTX
2354 variant has internal flash SS pulldown for boot mode
for CRSF receiver
gyro SPI line, seperate from blackbox
decoupling caps, place close to IC, one is enough for two adjacent pins
for external (extra)
Crystal per datasheet. 10pF loading plus some stray capacitance ~12pF
for external (GPS)
i2c for external sensors
WS2812 level shifting. Most accept 3.3v logic but 5v is more robust
status LED
RC lowpass filters on ADC and VREG like Pico datasheet
USB port
1.1V SMPS by RP datasheet inductor polarity important
buzzer with N-MOS low side switch
4.7u on opposite side of regulator

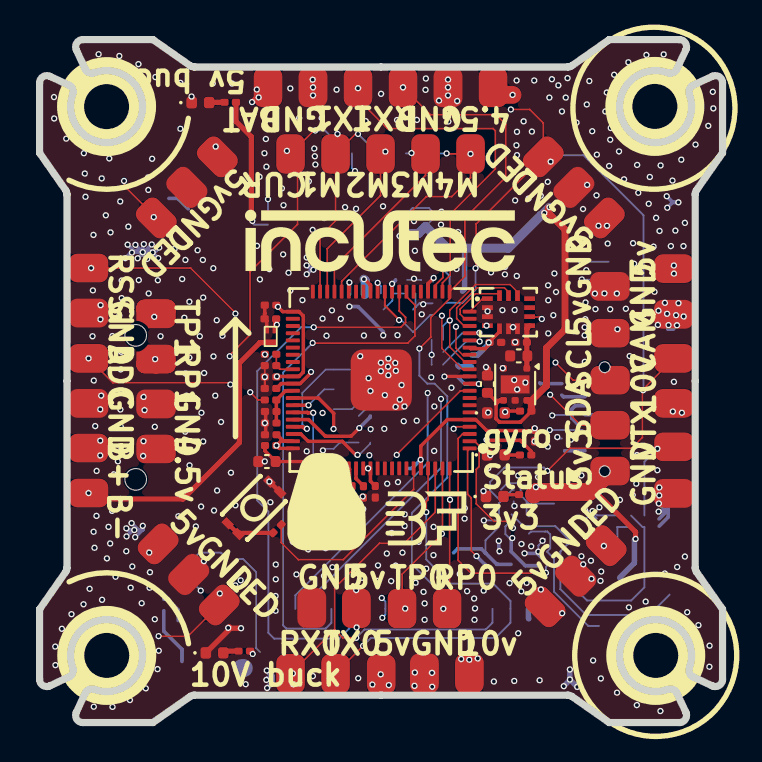
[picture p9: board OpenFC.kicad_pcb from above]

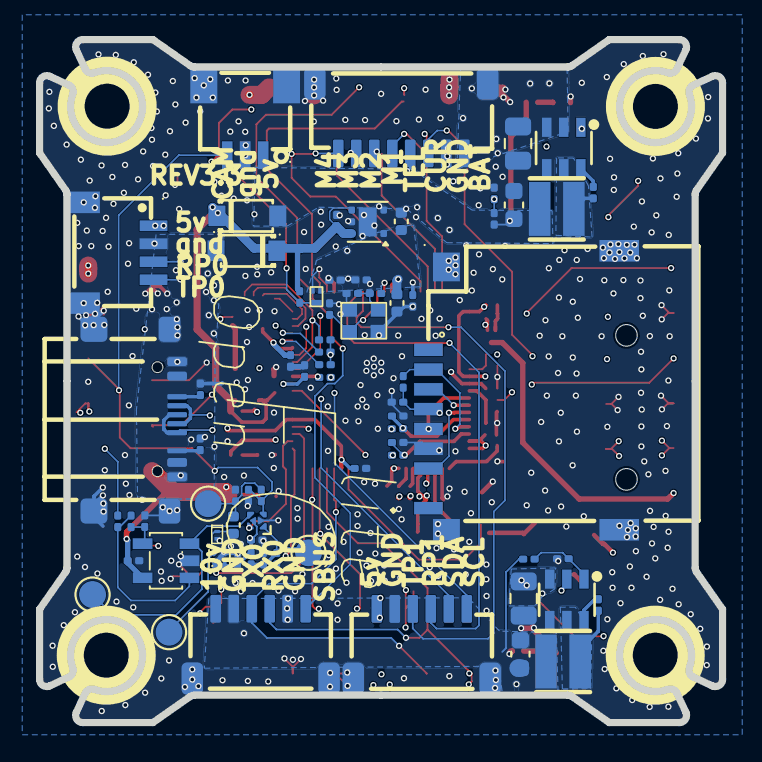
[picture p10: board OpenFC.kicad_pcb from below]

Board: 6 copper layers, 37.9 x 37.9 mm, 164 parts (72 on the bottom side), 82 nets.

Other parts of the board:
C35: 100n; C_0201_0603Metric
Card1: TF PUSH; TF-SMD_TF-PUSH
R30: 10k; R_0201_0603Metric

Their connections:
+3.3V: C35.1, Card1.4 (VDD), R30.1; also elsewhere on the board
/BLACKBOX/FLASH_CS: Card1.2 (CD/DAT3), R30.2; also elsewhere on the board
/BLACKBOX/SPI1.MISO: Card1.7 (DAT0); also elsewhere on the board
/BLACKBOX/SPI1.MOSI: Card1.3 (CMD); also elsewhere on the board
/BLACKBOX/SPI1.SCK: Card1.5 (CLX); also elsewhere on the board
GND: C35.2, Card1.6 (VSS), Card1.10, Card1.11, Card1.12, Card1.13; also elsewhere on the board

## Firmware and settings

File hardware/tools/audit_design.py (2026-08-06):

#!/usr/bin/env python3
"""
OpenFC-Lite Design Audit.

Parses the KiCad 10 design using kicad-skip (schematics) and pcbnew (PCB netlist)
and produces a comprehensive hardware inventory + Betaflight MFG validation report.

Run with KiCad's bundled Python so pcbnew is available:
  /Applications/KiCad/KiCad.app/Contents/Frameworks/Python.framework/Versions/Current/bin/python3 \
    hardware/tools/audit_design.py
"""

from __future__ import annotations

import collections
import os
import re
import sys
from pathlib import Path

HW = Path(__file__).resolve().parents[1]
ROOT_SCH = HW / "OpenFC.kicad_sch"
PCB = HW / "OpenFC.kicad_pcb"
OUT = HW / "tools" / "design_audit.md"

# ---------- Parsers ----------

# kicad-skip: KiCad's bundled Python does not see user-level pip installs.
# If kicad-skip lives outside the bundled interpreter's path, point the
# KICAD_SKIP_SITE_PACKAGES environment variable at its site-packages dir.
_extra_site = os.environ.get("KICAD_SKIP_SITE_PACKAGES")
if _extra_site:
    sys.path.insert(0, _extra_site)
try:
    from skip import Schematic
except ImportError:
    print("ERROR: kicad-skip not available. pip install kicad-skip", file=sys.stderr)
    sys.exit(1)

try:
    import pcbnew  # type: ignore
except ImportError:
    print("ERROR: pcbnew not on path. Run with KiCad bundled Python.", file=sys.stderr)
    sys.exit(1)


# ---------- Schematic walk ----------

def list_sheets(root_sch: Path):
    """Return list of (sheetname, sheetfile) pairs referenced from root."""
    s = Schematic(str(root_sch))
    out = []
    for sh in s.sheet:
        props = {p.name: p.value for p in sh.property}
        out.append((props.get("Sheetname", "?"), props.get("Sheetfile", "?")))
    return out


def collect_symbols(sch_path: Path):
    """Parse a schematic; return list of dicts per placed symbol."""
    try:
        s = Schematic(str(sch_path))
    except Exception as e:
        print(f"  WARN: cannot parse {sch_path.name}: {e}", file=sys.stderr)
        return []
    out = []
    for sym in s.symbol:
        try:
            lib_id = sym.lib_id.value
        except Exception:
            continue
        props = {p.name: p.value for p in sym.property}
        ref = props.get("Reference", "?")
        if ref.startswith("#"):
            continue  # power flag / gnd
        # Filter out stray power-flag symbols mis-refed in sub-sheets (e.g. blackbox
        # sub-sheet has U1..U9 that are actually +3.3V / GND power symbols).
        lib_id_lower = lib_id.lower()
        if lib_id_lower.startswith("power:") or lib_id_lower == "power":
            continue
        out.append({
            "sheet": sch_path.stem,
            "ref": ref,
            "value": props.get("Value", ""),
            "footprint": props.get("Footprint", ""),
            "mpn": props.get("MPN", ""),
            "lcsc": props.get("LCSC_Part", "") or props.get("LCSC", ""),
            "mfr": props.get("Manufacturer", ""),
            "description": props.get("Description", ""),
            "lib_id": lib_id,
            "dnp": bool(getattr(sym, "dnp", None) and sym.dnp.value),
            "on_board": bool(getattr(sym, "on_board", None) and sym.on_board.value),
        })
    return out


# ---------- PCB walk ----------

def load_pcb(pcb_path: Path):
    return pcbnew.LoadBoard(str(pcb_path))


def footprint_index(board):
    """ref -> {pads: {pad_num: netname}, funcs: {pad_num: pinfunc}, ...}"""
    idx = {}
    for fp in board.GetFootprints():
        r = fp.GetReference()
        pads = {}
        funcs = {}
        for pad in fp.Pads():
            num = pad.GetNumber()
            pads[num] = pad.GetNetname() or ""
            try:
                funcs[num] = pad.GetPinFunction() or ""
            except Exception:
                funcs[num] = ""
        idx[r] = {
            "value": fp.GetValue(),
            "footprint": fp.GetFPID().GetLibItemName().c_str() if hasattr(fp.GetFPID(), "GetLibItemName") else "",
            "pads": pads,
            "funcs": funcs,
        }
    return idx


def net_to_refpins(board):
    """netname -> list of (ref, pad_num, pad_name/function)"""
    d = collections.defaultdict(list)
    for fp in board.GetFootprints():
        r = fp.GetReference()
        for pad in fp.Pads():
            name = pad.GetNetname() or ""
            d[name].append((r, pad.GetNumber(), pad.GetPinFunction() if hasattr(pad, "GetPinFunction") else ""))
    return d


# ---------- Classification ----------

FUNC_RULES = [
    ("MCU",       lambda s: s["ref"].startswith("U") and "RP235" in s["value"].upper()),
    ("IMU",       lambda s: "LSM6" in s["value"].upper() or "ICM-4" in s["value"].upper() or "MPU6" in s["value"].upper()),
    ("Buck",      lambda s: s["ref"].startswith("U") and "LMR5" in s["value"].upper()),
    ("LDO",       lambda s: s["ref"].startswith("U") and ("LP5912" in s["value"].upper() or "NCV8187" in s["value"].upper())),
    ("Power Mux", lambda s: "TPS2116" in s["value"].upper()),
    ("OSD",       lambda s: "TLV3201" in s["value"].upper() or "TLV9061" in s["value"].upper() or "LVC1G3157" in s["value"].upper() or "PI3A223" in s["value"].upper()),
    ("SD card",   lambda s: "TF-" in s["value"].upper() or "SD" == s["ref"][:2].upper() and "CARD" in s["description"].upper()),
    ("USB",       lambda s: s["ref"].startswith("USB") or "USB" in s["value"].upper() and s["ref"].startswith("J") or s["ref"] == "USB1"),
    ("Switch",    lambda s: s["ref"].startswith("SW") or "TS2306" in s["value"].upper()),
    ("Connector", lambda s: s["ref"].startswith("J") or "CONN" in s["lib_id"].upper()),
    ("Test Pad",  lambda s: s["ref"].startswith("TP")),
    ("MOSFET",    lambda s: s["ref"].startswith("Q")),
    ("Diode/LED", lambda s: s["ref"].startswith("D") and ("LED" in s["value"].upper() or "LED" in s["description"].upper())),
    ("Diode",     lambda s: s["ref"].startswith("D")),
    ("Inductor",  lambda s: s["ref"].startswith("L")),
    ("Ferrite",   lambda s: s["ref"].startswith("FB")),
    ("Resistor",  lambda s: s["ref"].startswith("R")),
    ("Capacitor", lambda s: s["ref"].startswith("C")),
    ("IC",        lambda s: s["ref"].startswith("U")),
]

def classify(sym):
    for name, fn in FUNC_RULES:
        try:
            if fn(sym):
                return name
        except Exception:
            continue
    return "Misc"


# ---------- Report builders ----------

def refs_on_net(net2rp, netname, exclude_refs=None):
    exclude_refs = set(exclude_refs or [])
    return [(r, n, f) for (r, n, f) in net2rp.get(netname, []) if r not in exclude_refs]


def find_caps_between(syms_by_ref, net2rp, netname_a, netname_b="GND"):
    """Return list of cap refs having one pad on netname_a and other on netname_b."""
    caps_on_a = {r for (r, _, _) in net2rp.get(netname_a, []) if r.startswith("C")}
    caps_on_b = {r for (r, _, _) in net2rp.get(netname_b, []) if r.startswith("C")}
    return sorted(caps_on_a & caps_on_b, key=lambda x: int(re.sub(r"\D", "", x) or 0))


def find_nets_matching(net2rp, *patterns):
    pats = [re.compile(p, re.I) for p in patterns]
    return [n for n in net2rp if any(p.search(n) for p in pats)]


def pad_net(fp_idx, ref, pad_num):
    return fp_idx.get(ref, {}).get("pads", {}).get(str(pad_num), "")


def md_table(headers, rows):
    out = ["| " + " | ".join(headers) + " |",
           "|" + "|".join(["---"] * len(headers)) + "|"]
    for row in rows:
        out.append("| " + " | ".join(str(x) for x in row) + " |")
    return "\n".join(out)


# ---------- Main audit ----------

def main():
    lines = []
    W = lines.append

    W("# OpenFC-Lite Design Audit\n")
    W(f"Generated from `{ROOT_SCH.name}` + `{PCB.name}` via kicad-skip + pcbnew.\n")

    # ---- 1. Hierarchy ----
    W("## 1. Top-level Hierarchy\n")
    sheets = list_sheets(ROOT_SCH)
    rows = []
    for name, path in sheets:
        exists = (HW / path).exists()
        rows.append([name, f"`{path}`", "yes" if exists else "**MISSING**"])
    W(md_table(["Sheetname", "File", "On disk"], rows))
    W("")
    W(f"Root schematic: `{ROOT_SCH.name}`, {len(sheets)} sub-sheet(s) referenced.\n")

    # ---- 2. Components ----
    W("## 2. Component Inventory\n")
    all_syms = []
    for name, path in sheets:
        p = HW / path
        if p.exists():
            all_syms.extend(collect_symbols(p))
    # Deduplicate by ref (symbols may appear in multiple places due to power/gnd)
    seen = {}
    for s in all_syms:
        seen.setdefault(s["ref"], s)
    syms = list(seen.values())

    W(f"Total placed refs: **{len(syms)}** (DNP excluded: "
      f"{len([s for s in syms if s['dnp']])}).\n")

    by_func = collections.defaultdict(list)
    for s in syms:
        by_func[classify(s)].append(s)

    # Print ICs, regulators, connectors etc fully; print caps/resistors summarized
    DETAIL_FUNCS = ["MCU", "IMU", "Buck", "LDO", "Power Mux", "OSD",
                    "SD card", "USB", "Switch", "MOSFET",
                    "Diode/LED", "Diode", "IC", "Inductor", "Ferrite"]
    def ref_sort_key(ref):
        m = re.match(r"([A-Za-z]+)(\d+)", ref)
        if m:
            return (m.group(1), int(m.group(2)))
        return (ref, 0)

    for fn in DETAIL_FUNCS:
        items = sorted(by_func.get(fn, []), key=lambda x: ref_sort_key(x["ref"]))
        if not items:
            continue
        W(f"### {fn} ({len(items)})\n")
        rows = []
        for s in items:
            mpn = s["mpn"] or s["value"]
            dnp = " DNP" if s["dnp"] else ""
            rows.append([s["ref"] + dnp, s["value"], mpn, s["lcsc"] or "-",
                         s["mfr"] or "-", s["footprint"].split(":")[-1] if s["footprint"] else "-",
                         s["sheet"]])
        W(md_table(["Ref", "Value", "MPN", "LCSC", "Mfr", "Footprint", "Sheet"], rows))
        W("")
    # Connector summary only (detail in section 14)
    conns = by_func.get("Connector", [])
    if conns:
        W(f"### Connector / Solder Pads ({len(conns)})\n")
        W("(full net list in section 14)\n")
        # group by footprint
        fp_count = collections.Counter((s["footprint"].split(":")[-1] or "-", s["sheet"]) for s in conns)
        rows = [[fp, sh, c] for (fp, sh), c in sorted(fp_count.items())]
        W(md_table(["Footprint", "Sheet", "Count"], rows))
        W("")

    # Passives summary
    W("### Passives summary\n")
    rows = []
    for fn in ("Resistor", "Capacitor", "Test Pad"):
        items = [s for s in by_func.get(fn, []) if not s["dnp"]]
        dnp = [s for s in by_func.get(fn, []) if s["dnp"]]
        rows.append([fn, len(items), len(dnp)])
    W(md_table(["Function", "Placed", "DNP"], rows))
    W("")

    # ---- Load PCB for net-level analysis ----
    board = load_pcb(PCB)
    fp_idx = footprint_index(board)
    net2rp = net_to_refpins(board)

    # ---- 3. Power tree ----
    W("## 3. Power Tree\n")
    W("```")
    W("+BATT -> U6 (LMR51420YFDDCR buck) -> +12V   [switchable via GPIO11 via Q?]")
    W("+BATT -> U7 (LMR51420YFDDCR buck) -> +5V_BUCK")
    W("+5V_BUCK -+")
    W("          +- U33 (TPS2116 mux) -> +5V")
    W("VBUS(USB)-+")
    W("+5V -> U13 (LP5912-3.3) -> +3.3V")
    W("+3.3V -> U36 (RP2354B VREG) -> +1.1V_CORE (DVDD)")
    W("+5V -> U21 (NCV8187 LDO) -> +1.8V_GYRO")
    W("```\n")

    regs = [
        ("U6",  "LMR51420YFDDCR", "12V buck"),
        ("U7",  "LMR51420YFDDCR", "5V buck"),
        ("U13", "LP5912-3.3DRVR", "3.3V LDO"),
        ("U21", "NCV8187AMT180TAG", "1.8V gyro LDO"),
        ("U33", "TPS2116DRLR", "5V power mux"),
    ]
    rows = []
    for ref, mpn, role in regs:
        fp = fp_idx.get(ref, {})
        pads = fp.get("pads", {})
        # summarise input / EN / output if we can infer by pin function from schematic
        # Just print key pads
        rows.append([ref, role, mpn, fp.get("footprint", "-"),
                     "; ".join(f"{k}→{v}" for k, v in sorted(pads.items(), key=lambda x: int(x[0]) if x[0].isdigit() else 99))])
    W(md_table(["Ref", "Role", "MPN", "Footprint", "Pad → Net"], rows))
    W("")

    # ---- 4. Bypass caps per rail ----
    W("## 4. Bypass caps per power rail\n")
    rails = ["+BATT", "+12V", "+5V_BUCK", "+5V", "VBUS", "+3.3V", "+1.8V_GYRO",
             "+1.1V", "+1.1V_CORE", "DVDD"]
    rows = []
    for rail in rails:
        # try exact, then with leading /
        candidates = [rail, "/" + rail, rail.lstrip("+"), "/" + rail.lstrip("+")]
        found_net = None
        for c in candidates:
            if c in net2rp:
                found_net = c
                break
        if not found_net:
            # try loose match
            loose = [n for n in net2rp if n.strip("/+").upper() == rail.strip("/+").upper()]
            if loose:
                found_net = loose[0]
        if not found_net:
            rows.append([rail, "- (net not found)", "-", "-"])
            continue
        caps = find_caps_between({}, net2rp, found_net, "GND")
        # count how many pins are on this net (fanout size)
        fanout = len(net2rp.get(found_net, []))
        rows.append([rail, found_net, len(caps), ", ".join(caps) if caps else "-"])
    W(md_table(["Rail", "Net", "# Caps to GND", "Cap refs"], rows))
    W("")
    # Also report ALL nets that look like rails
    rail_like = [n for n in net2rp if re.search(r"(^|/)(\+?\d+V|VBUS|VBAT|VDD|AVDD|DVDD|VREG)", n, re.I)]
    W("Rail-like nets present:\n")
    W(", ".join(f"`{n}`" for n in sorted(set(rail_like))))
    W("")

    # ---- 5. ADC inputs ----
    W("## 5. ADC Inputs\n")
    adc_nets = {
        "VBAT_SENSE": ["VBAT", "VBATT_SENSE", "VBAT_ADC", "BATT_ADC", "VBAT_SCALE", "BATTERY_ADC"],
        "CURR_SENSE": ["CURRENT", "I_SENSE", "CURR_ADC", "CURR_SENSE", "IMON", "CURRENT_ADC"],
        "RSSI":       ["RSSI", "RSSI_ADC"],
        "EXT":        ["EXT_ADC", "ADC_EXT", "EXT"],
    }
    # Try to find the MCU's actual ADC pins: GPIO40,41,45,47 per CLAUDE.md
    mcu_ref = "U36"
    mcu_fp = fp_idx.get(mcu_ref, {})
    # The ADC nets go to MCU pins: find them by following net back to U36
    rows = []
    for role, candidates in adc_nets.items():
        net = None
        for c in candidates:
            match = [n for n in net2rp if c.upper() in n.upper()]
            if match:
                net = sorted(match, key=len)[0]
                break
        if not net:
            rows.append([role, "- not found", "-", "-", "-"])
            continue
        # Find MCU pad carrying this net
        mcu_pad = "-"
        for p, n in mcu_fp.get("pads", {}).items():
            if n == net:
                mcu_pad = p
                break
        # Find resistors on the net
        res = [r for (r, _, _) in net2rp.get(net, []) if r.startswith("R")]
        caps = find_caps_between({}, net2rp, net, "GND")
        rows.append([role, net, mcu_pad,
                     ", ".join(sorted(set(res))) or "-",
                     ", ".join(caps) or "**NONE**"])
    W(md_table(["Role", "Net", "MCU pad", "Resistors on net", "Bypass caps to GND"], rows))
    W("")
    W("**Check**: A CURRENT-sense ADC input WITHOUT a bypass cap at the MCU pin is a "
      "Betaflight MFG-guideline violation (noise couples straight into ADC).\n")

    # ---- 6. SPI buses & CS pull-ups ----
    W("## 6. SPI Buses & CS pull-ups\n")
    spi_nets = {
        "SPI0 SCK":  [n for n in net2rp if re.search(r"SPI0?_?SCK|GYRO_?SCK|IMU_?SCK", n, re.I)],
        "SPI0 MOSI": [n for n in net2rp if re.search(r"SPI0?_?(MOSI|SDI|SDA)|GYRO_?MOSI|IMU_?MOSI", n, re.I)],
        "SPI0 MISO": [n for n in net2rp if re.search(r"SPI0?_?(MISO|SDO)|GYRO_?MISO|IMU_?MISO", n, re.I)],
        "IMU CS":    [n for n in net2rp if re.search(r"(IMU|GYRO).*CS|CS_?(IMU|GYRO)", n, re.I)],
        "SD CS":     [n for n in net2rp if re.search(r"SD.*CS|CS_?SD|BB_?CS", n, re.I)],
        "SD MOSI":   [n for n in net2rp if re.search(r"SD.*MOSI|SD.*DI|SD_?CMD", n, re.I)],
        "SD MISO":   [n for n in net2rp if re.search(r"SD.*MISO|SD.*DO|SD_?DAT0?", n, re.I)],
        "SD SCK":    [n for n in net2rp if re.search(r"SD.*SCK|SD.*CLK", n, re.I)],
    }
    rows = []
    for role, nets in spi_nets.items():
        if not nets:
            rows.append([role, "-", "-", "-"])
            continue
        net = nets[0]
        # list refs on that net
        refs = sorted(set(r for (r, _, _) in net2rp[net]))
        # resistors on net (pull-up candidates)
        rs = [r for r in refs if r.startswith("R")]
        rows.append([role, net, ", ".join(refs), ", ".join(rs) or "-"])
    W(md_table(["Signal", "Net", "Refs on net", "Resistors (pull-ups?)"], rows))
    W("")

    # Specific checks for CS pull-ups
    W("### CS pull-up check (to +3.3V)\n")
    cs_checks = []

    def find_cs_pad(ref):
        """Return (pad_num, netname) for the CS pin of a footprint, using pin function."""
        fp = fp_idx.get(ref, {})
        for p, func in fp.get("funcs", {}).items():
            if re.search(r"(^|_)CS(_|$)", func or "", re.I):
                return p, fp.get("pads", {}).get(p, "")
        return None, None

    # IMU CS -> U14 using pin function
    pad, net = find_cs_pad("U14")
    cs_checks.append((f"IMU_CS (U14 pad {pad})", net))
    # SD CS -> Card2 pad 2 (TF-021B-H265 pinout: pin2=CS/DAT3)
    for ref, fp in fp_idx.items():
        v = fp.get("value", "").upper()
        if "TF-" in v or "MICROSD" in v:
            # TF socket pad 2 = CS in SPI mode
            n = fp.get("pads", {}).get("2", "")
            cs_checks.append((f"SD_CS ({ref} pad 2)", n))
            break
    rows = []
    for role, net in cs_checks:
        if not net:
            rows.append([role, "-", "-", "-"])
            continue
        rs = [r for (r, _, _) in net2rp.get(net, []) if r.startswith("R")]
        # Does any of those R's touch +3.3V or +3V3?
        has_pullup = False
        pu_ref = "-"
        for rref in rs:
            rpads = fp_idx.get(rref, {}).get("pads", {})
            other_nets = set(rpads.values()) - {net}
            if any(re.search(r"3V3|3\.3V|VDDIO", x, re.I) for x in other_nets):
                has_pullup = True
                pu_ref = rref
                break
        rows.append([role, net, "YES" if has_pullup else "NO", pu_ref])
    W(md_table(["CS line", "Net", "Pull-up present?", "Pull-up ref"], rows))
    W("")

    # ---- 7. Status LEDs ----
    W("## 7. Status LEDs (non-WS2812)\n")
    leds = [s for s in syms if s["ref"].startswith("D") and
            ("LED" in s["value"].upper() or "LED" in (s["description"] or "").upper())]
    rows = []
    for led in sorted(leds, key=lambda x: x["ref"]):
        ref = led["ref"]
        fp = fp_idx.get(ref, {})
        pads = fp.get("pads", {})
        # LEDs usually have A/K or 1/2
        pin_nets = ", ".join(f"{k}→{v}" for k, v in pads.items())
        # Try to identify MCU pin driving it (non-rail end)
        drivers = [v for v in pads.values() if not re.search(r"\+?(\d+V|GND|VBUS|VBAT)", v, re.I)]
        rows.append([ref, led["value"], led["mpn"] or "-", pin_nets, ", ".join(drivers) or "-"])
    W(md_table(["Ref", "Value/Color", "MPN", "Pad nets", "Likely MCU-side net"], rows))
    W("")
    # Blue LED check
    blue = [l for l in leds if "BLUE" in l["value"].upper() or "BLU" in l["value"].upper()]
    W(f"Blue LED (Betaflight LED0 requirement): **{'PRESENT' if blue else 'MISSING'}** "
      f"({', '.join(l['ref'] for l in blue) or 'none'})\n")

    # ---- 8. I2C ----
    W("## 8. I2C Pull-ups\n")
    sda_net = [n for n in net2rp if re.search(r"I2C.*SDA|SDA$|/SDA", n, re.I)]
    scl_net = [n for n in net2rp if re.search(r"I2C.*SCL|SCL$|/SCL", n, re.I)]
    rows = []
    for role, nets in (("I2C_SDA", sda_net), ("I2C_SCL", scl_net)):
        if not nets:
            rows.append([role, "-", "-", "-"])
            continue
        net = nets[0]
        refs = sorted(set(r for (r, _, _) in net2rp[net]))
        rs = [r for r in refs if r.startswith("R")]
        has_pullup = False
        for rref in rs:
            rpads = fp_idx.get(rref, {}).get("pads", {})
            if any(re.search(r"3V3|3\.3V|VDDIO", x, re.I) for x in rpads.values()):
                has_pullup = True
                break
        rows.append([role, net, ", ".join(refs), "YES" if has_pullup else "**NO**"])
    W(md_table(["Signal", "Net", "Refs on net", "Pull-up to 3.3V"], rows))
    W("")

    # ---- 9. MCU pinout ----
    W("## 9. RP2354B (U36) Pinout\n")
    mcu_fp = fp_idx.get("U36", {})
    pads = mcu_fp.get("pads", {})
    rows = []
    for p in sorted(pads.keys(), key=lambda x: int(x) if x.isdigit() else 999):
        n = pads[p]
        # skip internal / power pads for clarity (keep but mark)
        rows.append([p, n])
    W(md_table(["Pad", "Net"], rows))
    W("")

    # ---- 10. OSD circuit ----
    W("## 10. OSD Circuit\n")
    osd_refs = [s["ref"] for s in syms if s["ref"] in ("U34", "U35", "U38")]
    rows = []
    for ref in osd_refs:
        fp = fp_idx.get(ref, {})
        rows.append([ref, fp.get("value"), fp.get("footprint"),
                     "; ".join(f"{k}→{v}" for k, v in fp.get("pads", {}).items())])
    W(md_table(["Ref", "Value", "Footprint", "Pad → Net"], rows))
    W("")
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

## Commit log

2026-06-17 Re-route with connectors
    [OpenFC.kicad_pcb, pads.kicad_sch, rp2350a.kicad_sch]
2026-08-04 chore: wire shared Incutec KiCad library
    Adds incutec-hw/KiCad-Library as submodule at libs/KiCad-Library, pinned
    to the feat/complete-library build. Project lib tables gain the Incutec
    sym+fp entries via ${KIPRJMOD} relative paths. Existing local libraries
    untouched (frozen, see the library repo MANIFEST).
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2026-08-05 hardware: add LP5912-1.8 LDO (U15) and layout working state
    - New LP5912-1.8DRVR symbol in project lib, WSON-6 2x2mm footprint with
    thermal vias, matching STEP model
    - LP5912-1.8 added to power sheet as U15
    - OpenFC.kicad_pcb layout working state carrying the change
    - .kicad_pro used_designators updated (U15)
    [OpenFC.kicad_pcb, power.kicad_sch]
2026-08-05 hardware: add OpenFC_Panel panelization project
    [OpenFC_Panel.kicad_pcb]
2026-08-05 docs: add Rev 3 changelist from Rev 2 bring-up
    Running defect/decision list: GND shorts on GPIO0-3/28/31, reversed gyro
    LED, production IMU decision, collected during Rev 2 bring-up and flight
    testing.
2026-08-05 docs: adopt OpenDrone repo standard
    Rewrite README to the standard section order, add CONTRIBUTING.md,
    AGENTS.md, CHANGELOG.md, and hardware/docs/DESIGN.md. Deep design
    detail (power tree, connectivity, connectors, OSD chain, firmware)
    moves from README to DESIGN.md, verified against the current
    schematic netlist. Move REV3_CHANGELIST.md to hardware/docs/.
    Fact fixes: FB_OSD merged upstream (betaflight#14882, 2026-04-22),
    dead wiki link removed, KiCad 10, microSD slot is TF PUSH (C393941),
    P1 is SMD, submodule clone step documented, repo layout lists only
    committed paths.
2026-08-05 build: track fabrication-toolkit-options.json
    Stop gitignoring the Fabrication Toolkit config and commit it so
    production exports are reproducible, matching OpenESC-30x30.
2026-08-05 docs: fix verified part facts and tools description
    - Q1/Q2 are AP1606 per schematic Value/MPN/LCSC, not the DMN1150UFB-7B
    library default
    - crystal X1: full MPN and LCSC C37635340
    - restore verified facts dropped from the old README: USB D+/D- 30 ohm
    series resistors (R10/R11), 10V buck FB divider 100k:6.49k (about
    9.85 V) and 22 uF output cap
    - OSD video output leaves on pad J34; the U8 VTX connector has no
    video pin
    - hardware/tools is not read-only: several scripts modify design files
2026-08-05 Fix verification findings: style, slugs, depersonalization
    - Replace em dashes with hyphen, comma, or colon in audit_design.py,
    openfc_connectivity_report.py, design_audit.md, rp2350_layout_notes.md
    - audit_design.py: replace hardcoded user site-packages sys.path entry
    with KICAD_SKIP_SITE_PACKAGES environment variable lookup
    - REV3_CHANGELIST.md: depersonalize maintainer reference
    [audit_design.py]
2026-08-06 Rewrite CONTRIBUTING for humans: file locking, render proof, sign-off
    KiCad files cannot be merged, so the doc now leads with claiming files via
    git lfs lock and issue-first discussion, the convention used by LumenPnP and
    Ultimate Hacking Keyboard. Adds .gitattributes marking design files lockable.
    Drops the internal documentation-style rule that meant nothing to contributors.
2026-08-06 Fix contradictions and duplicated information
    Docs contradicted the design files and each other. Verified every claim
    against hardware/*.kicad_sch and hardware/OpenFC.kicad_pcb before writing.
    Contradictions:
    - DESIGN.md: document that the 1.8 V gyro LDO is U15 LP5912-1.8DRVR in the
    schematic but U6 NCV8187AMT180TAG on both the board and the production
    panel, so fabricated boards ship with the NCV8187. Logged as an open Rev 3
    decision with the schematic-only pads J45/J46.
    - EMC_CHECKLIST.md: LMR51420/30 -> LMR51430 (U3/U4 are LMR51430YFDDCR,
    C5219261); NCV8187 -> part-agnostic "1.8 V gyro LDO"; USB series R
    27 ohm -> 30 ohm with the real refs R10/R11 (R7/R8 are 1k ADC filters).
    -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
    [audit_design.py]
2026-08-06 Local libraries are the working default again
    New parts go into this repo's local libraries. KiCad-Library becomes a mirror
    of parts we already use or stock, worth checking first because a hit means we
    have sourced it before. Promotion into it is a separate step.
2026-08-06 Swap 1.8V LDO and IMU, fix BOM/CPL export hygiene
    Mirrors the same pass done on OpenFC-Lite-Mini.
    Part changes:
    - NCV8187AMT180TAG (stock 0 at JLC) replaced by U15 LP5912-1.8DRVR
    (C2876234), same WSON-6 2x2 land pattern as the LP5912-3.3, PG retained.
    - U9 LSM6DSV16XTR replaced by BMI270 (C2836813) in the schematic. Bosch
    Table 22 matches the existing LGA-14 symbol pin for pin, so no rewire.
    Export fixes:
    - U15, CN1 and U13 carried their part numbers in a field named "LCSC Part"
    rather than "LCSC" and exported blank. Renamed. CN1 (C160404) and U13
    (C160403) are real JST connectors and stay in the BOM.
    - J3, J6, J10, J16, J19, J23 (lib:small_pad) and TP1 to TP4 (TestPoint) were
    st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
    [OpenFC.kicad_pcb, imu.kicad_sch, osd.kicad_sch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]
2026-08-08 Fix SOD-882 3D offset in lib, re-render board images
    The SOD-882 (RB161QS-40 RPP diodes D2/D3) library footprint carried an
    EasyEDA absolute-coordinate 3D offset of (-911.61, 887.73) mm, so the
    diode models rendered a kilometre off the board. Library fixed to zero
    offset via the pcbnew API. The matching board-instance fix lives in the
    working tree together with the in-progress Rev3 layout changes and will
    be committed with them; these renders are taken from that current state,
    so both diodes are now visible and every IC verified present.
2026-08-11 docs: 8S input, LMR51635 bucks, Discord-first contributing
    README and DESIGN.md now state 3S-8S and the LMR51635YDDCR bucks (U6/U16,
    C45262770) with the 0.8 V reference dividers 100k:8.87k for 9.82 V and
    100k:19.1k for 4.99 V.
    DESIGN.md drops the resolved IMU and 1.8 V LDO ambiguities: U9 is BMI270 and
    U15 is LP5912-1.8DRVR in schematic, BOM and board.
    REV3_CHANGELIST.md splits into implemented and open. The gyro LED entry is
    corrected: D9 hangs off the LDO power good pin through R39 6.49k, giving about
    0.32 mA against 0.78-0.95 mA for the other indicators, so the recorded 180
    degree mounting error does not explain it.
    CONTRIBUTING.md now asks contributors to raise proposals in Discord an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
2026-08-11 docs: correct the gyro LED root cause in the Rev 3 changelist
    D9, R39 and U15 are absent from the Rev 2 layout entirely. They exist in the
    Rev 2 schematic but were never placed; the board carried an unused
    NCV8187AMT180TAG footprint instead. D4, D5, D7 and their series resistors are
    all present on Rev 2, which is why only the gyro indicator looked dead. The
    recorded 180 degree mounting error does not explain it.
    All three parts are placed on the current board with clean parity, so the
    indicator works. What remains is a brightness choice on R39.
2026-08-11 Rev 3: 8S bucks, LP5912 gyro LDO, BMI270, drop the panel project
    Power: both bucks are LMR51635YDDCR (U6, U16, C45262770), 4.3-60 V with a 63 V
    absolute maximum, replacing the LMR51430YFDDCR whose 38 V absolute maximum left
    no margin at 8S. The reference moves from 0.6 V to 0.8 V so the feedback
    dividers follow: R22 8.87k for 9.82 V and R24 19.1k for 4.99 V. Same SOT-23-6
    land pattern, different pinout, so both buck corners are re-routed.
    Gyro supply: U15 LP5912-1.8DRVR placed, along with D9 and R39 which existed in
    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
    [OpenFC.kicad_pcb, OpenFC_Panel.kicad_pcb, osd.kicad_sch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]
2026-08-13 Add prebuilt Betaflight uf2 for Rev 2 (#17)
    Target OPENFC_LITE_RP2350B, 2026.6.0-alpha, built from
    Just4Stan/betaflight branch pico-enable-osd-hd.
    Carries the Rev 2 pin workaround for the GND shorts on GPIO0-3,
    GPIO28 and GPIO31, so the active IO mapping does not match the
    silkscreen. Rev 3 fixes the shorts and retires the workaround.
    The binary is a Betaflight build and stays under GPL-3.0.
2026-08-13 Standardise: AGENTS.md, trimmed README, canonical dotfiles, design rules (#18)
    Adopts the org-wide shape, matching the ESC and RX repos. Four root files,
    CONTRIBUTING is a stub pointing at OpenDrone-hw/.github.
    AGENTS.md replaces hardware/docs/DESIGN.md and the gitignored CLAUDE.md, and
    absorbs the EMC checklist and layout notes that were sitting in hardware/tools/.
    It states in the Repo table that this project is called OpenFC in both FC repos,
    which is the ambiguity that has already caused a part to be imported into the
    wrong one.
    hardware/OpenFC.kicad_dru now carries the canonical block. On OpenFC-Lite the
    file existed on disk but was gitignored and untracked, so the design intent had
    n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
2026-08-13 README: standardised link row, specs from the shop, status badge (#19)
    Same shape in every board repo.
    Outbound links move out of prose into one badge row: status, shop, the product's
    Discord channel, its build video, and OSHWA where the board is certified. The
    status badge links to the stage ladder in the org CONTRIBUTING rather than
    describing the stage here.
    The specification table is synced from the product page on opendrone.be, which
    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
2026-08-14 Drop helpers that live in OpenDrone-Scripts
    The openfc_* extract/report trio and set_edgecuts_width.py have their
    canonical copies in software/OpenDrone-Scripts/kicad. add_mpn_fields.py
    stays: it hardcodes this repo's root-sheet list. audit_design.py stays:
    the two OpenFC copies have drifted and are board-specific.
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2026-08-14 Normalise board setup to the line standard
    The canonical dru's copper-to-copper rule demanded 0.1 mm outer
    clearance against the 0.09 line standard stated in the same file,
    flooding DRC with false errors on standard-routed boards. Removed;
    the project-file floors gate this already. Rule floors set to the
    line standard where the routed board complies, verified by DRC:
    zero new violations.
2026-08-14 Drop the KiCad-Library submodule: nothing references it
    No symbol, footprint or 3D model in the design resolves through
    libs/KiCad-Library; every part is in the repo's local libraries. The
    submodule only cost --recursive clones and pin maintenance. Lib-table
    rows for the dead Incutec nickname removed so KiCad stops warning.
2026-08-14 Raise rule floors to the line standard
    The 214 vias at 0.3/0.2 now violate the 0.35 via and 0.075 annular
    floors by design: they get enlarged to 0.35 manually, and the errors
    mark exactly which ones. Last board off the line standard.
2026-08-14 4V5 rework: TPS2116 mux replaced by DSK24 diode-OR
    U5, its RB161QS diodes, R19/R20 and C28 removed. D6 from the buck
    output and D10 from +5V_USB feed the new +4v5 net, which supplies the
    3.3 V and 1.8 V LDOs, the 6-pin JST and the J5/J47 pads. The buck
    output is plain +5V and drives the external 5 V pads directly. All 596
    vias at 0.35/0.2, so the line-standard floors pass. DSK24 footprint and
    3D model committed with the change. DRC severity choices per Stan.
    [OpenFC.kicad_pcb, pads.kicad_sch, power.kicad_sch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]
2026-08-14 Rebuild E6 substitute STEP models from the trusted wrl geometry
    The .step files beside these .wrl models were different parts (USB-C
    3.5x oversized, etc), and the upstream LCSC .step is the same wrong
    file, so kicad-cli --subst-models shipped wrong geometry in every STEP
    export while the 3D viewer looked perfect. Rebuilt as tessellated STEP
    solids from the .wrl the viewer renders, via
    OpenDrone-Scripts/kicad/wrl_to_step.py: bbox and origin now match to
    0.000 mm. check_models reports zero E6, export unblocked.
    [OpenFC.kicad_pcb]
2026-08-14 Rev 3.1 release prep: renders, 4V5 power tree, revisions
    The committed board now matches the verified fab export exactly
    (check_export.py C1-C3 clean). Renders regenerated from it.
2026-08-15 docs: standardise AGENTS.md and spec table to Rev 3.1
    AGENTS.md rebuilt on the org template, netlist-verified at Rev 3.1 (BMI270, LMR51635 bucks, DSK24 diode-OR). README spec table completed: 4 UARTs, 3-8S input, 3.5 A BEC, dimensions, maintainer. DOC t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
2026-08-15 docs: add voltage range to input spec
    Input row now reads 3-8S LiPo (9.0-33.6 V).
2026-08-20 fix(lib): use KIPRJMOD for the SOD-123 3D model path
    The footprint and its two board instances carried an absolute /Users path, so
    the model resolved on one machine only and leaked a home directory into a
    public repo. Board file written through the pcbnew API, two lines changed and
    nothing else re-serialised.
    [OpenFC.kicad_pcb]
2026-08-22 3D models: retarget to KiCad stock, fix placement
    Replaces easyeda2kicad 3D models with KiCad's own where a dimension-matched
    equivalent exists. The easyeda models run 20-100x denser for the same package
    and most carry the LCEDA watermark modelled as raised geometry, which renders
    on every CAD picture of the board and is not on the real part.
    Only the (model ...) reference, offset and rotation are touched. No footprint,
    pad, land pattern, net, placement or value is modified. Applied to the footprint
    LIBRARY and the boards together: fixing only the .pretty is invisible because
    each board carries its own footprint copy, and fixing only the .kicad_pcb is
    surface level because the next placemen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
    [OpenFC.kicad_pcb]
2026-08-22 Rebuild the E6 substitute STEPs as solids
    The previous rebuild sewed the .wrl meshes into shells and wrote those,
    so all seven imported as loose surfaces. TF-SMD_TF-PUSH was also visibly
    broken: its card cage is authored open, and an open shell shades with
    backfaces. Regenerated with the fixed wrl_to_step.py.
    TF-PUSH is now 21 solids, 0 open shells, 0 invalid. Bounding box and
    origin are unchanged to 0.0000 mm on all seven, so check_models reports
    zero E6 and the board export is unaffected in size or placement.
    USB-C and X2SON keep a few open shells where a boundary loop is not a
    simple polygon; that is the source .wrl, not the conversion.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
2026-08-22 Replace the USB-C 3D model with a clean B-rep, 34.3 -> 0.51 MB
    The easyeda model was a 13,715-face tessellation carrying an LCEDA
    watermark. This one is a real B-rep: 34 solids, 319 faces, no watermark,
    and it drops the OpenFC-Lite board export from 37.8 to 24.8 MB.
    It is a substitute, not the same part. It has 16 signal contacts against
    the QTWT's 12, and is 0.56 mm wider and 0.45 mm deeper. Placed by
    bounding-box centre, +2.093 mm in Y, which splits the extra depth evenly:
    all 16 pins land inside the 12 pad rectangles, and the mouth clears the
    board edge by 1.50 mm against the old model's 1.27 mm. Z is unchanged,
    the two models already agreed there to 0.08 mm.
    The .wrl is regenerated fro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
2026-08-22 Rebuild the six mesh-derived STEPs with consistent winding
    The pushbutton was rendering inside-out: back faces over most of one flank
    and a slab across the middle. Cause was mixed triangle winding in the
    source .wrl, invisible in KiCad because those files are `solid FALSE`, but
    fatal once the mesh is sewn into a solid.
    Bounding box and origin unchanged to 0.0000 mm, check_models still 0 E6.
2026-08-25 schematics: complete Manufacturer/MPN coverage, trim stray whitespace
    16 field fixes: Manufacturer backfilled from the LCSC catalogue on osd,
    power and rp2350a sheets, trailing space trimmed from four XL-1005UGC MPNs.
    Part of the fab-agnostic BOM standardisation for quoting outside JLCPCB.
    kicad-skip reflowed the touched files; structural diff against the originals
    shows only property changes, ERC identical (179 violations before and after).
    [osd.kicad_sch, power.kicad_sch, rp2350a.kicad_sch]
2026-08-25 lib: fill LCSC, Manufacturer and MPN on placed library symbols
    Copied from the standardised schematic instances: 13 symbols gain
    missing fields, including LCSC numbers for LP5912-1.8DRVR, SM03B
    and SM04B. DMN1150UFB-7B and LSM6DSV16XTR left alone: their placed
    instances carry substitute parts (AP1606 C2849580, BMI270 C2836813),
    needs a human call.
2026-08-25 Rebrand silkscreen to incutec, final rev3.3 pass (Stan)
    [OpenFC.kicad_pcb]
2026-08-25 AGENTS: record rev3.3; rev silk synced by pipeline
    [OpenFC.kicad_pcb]
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2026-08-31 AGENTS.md: sync from the bench mirror rework (#34)
    Formatting repairs plus verified corrections from the 2026-08-31 bench
    session (fact-checked against datasheets, board READMEs and firmware
    sources). Details per file in OpenDrone-Testing commit 06034b3.
2026-09-01 chore: standardize OPENFC-LITE-3030 assets and guidance
    [OpenFC.kicad_pcb]
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2026-09-18 Align AGENTS.md with template conventions (#35)
    * Align AGENTS.md with template conventions
    Claude-Session: https://claude.ai/code/session_01GiFxVPcfpNcHY5feGsgG83
    * Reorder AGENTS.md sections: design first, agent mechanics last
    New order: Architecture, (Voltage envelope,) Power, Key parts, Connectors
    and I/O, (GPIO map, Using it on a base,) Layout rules, Firmware, Repo,
    (Parts and datasheets,) Environment, Rules, Revisions.
    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
2026-09-24 docs: rename stale rev2 photo files to match current board (#37)
    images/openfc-lite-rev2-{top,bottom}.png were re-rendered on 2026-08-25
    ("Re-render README images with incutec silkscreen") to show the current
    Rev3.3 incutec-branded board, but the filenames still said rev2. Renamed to
    images/{front,back}.png, matching the OpenESC-20x20/OpenESC-30x30
    convention, and updated README.md. Grepped the workspace: nothing outside
    this repo references the old filenames.
2026-10-05 docs: footnote that the flight controller also runs on 2S (#43)
    Published minimum stays 3S. The Input row gets an asterisk and a one-line
    footnote (founder decision, 2026-10-05). Verified from schematics, not
    bench-tested.
2026-10-25 docs: blank OSD with the LED strip on, workaround and pending fix (#51)
    The LED strip and FB OSD share PIO2 by default, so the analog OSD stays
    blank while LED_STRIP is on. Records the workaround, the config fix, this
    board's PIO1 state machine budget (two PIO UARTs + LED strip), the upstream
    PRs, and what a new image needs before it replaces the current one. The LED
    pad (Q2) is a non-inverting level shifter and needs no inversion.
2026-11-11 chore: KiCad 10 project settings re-save (#52)
    KiCad 10 rewrites the project file on save: the zone defaults block is written out in full (KiCad defaults, min_clearance unchanged), the net colour entry of the no longer existing +5V_BUCK net is dropped, and the text variables are sorted alphabetically. No design rule, net class or schematic content changes.
2026-11-11 fix: restore the +5V_BUCK net colour dropped by the project re-save (#53)
    The re-save merged in #52 removed the net colour of +5V_BUCK. The net still exists in power.kicad_sch, so the entry is restored. Display colour only.
2026-11-11 docs(rules): kicad-skip cannot round-trip KiCad 10 schematics (#54)
    Syncs the shared Rules section from OpenDrone-hw/hardware-template (PR 16).
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
